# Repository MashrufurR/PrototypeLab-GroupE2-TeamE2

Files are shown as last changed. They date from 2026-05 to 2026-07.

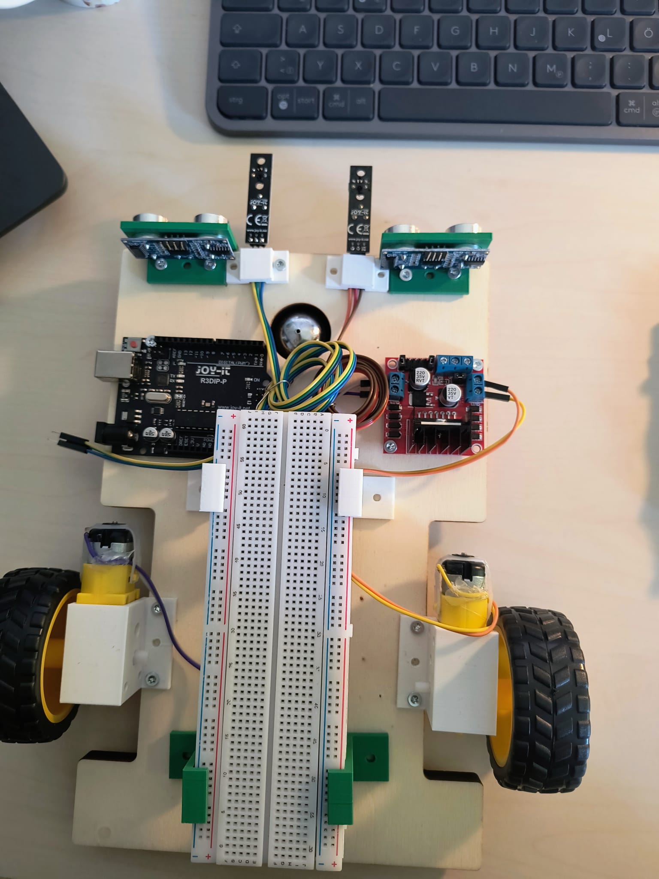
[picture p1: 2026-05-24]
Task1/Final Assemble Update/ Final Assemble.jpg

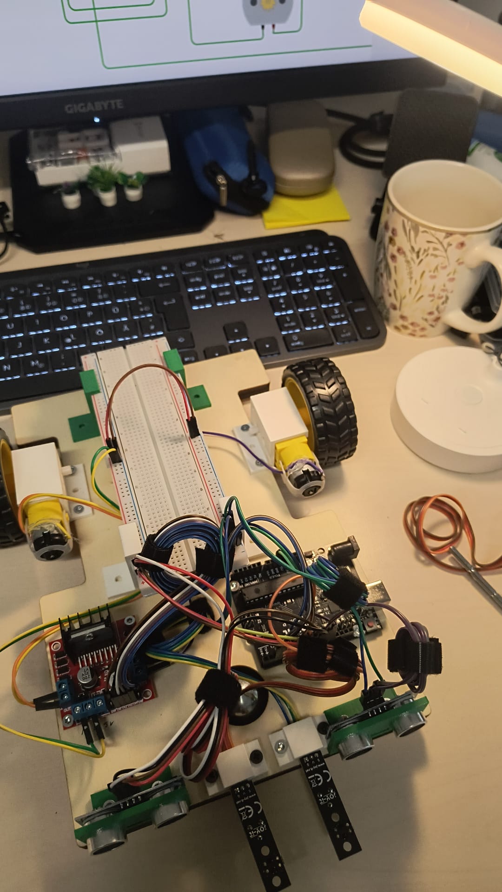
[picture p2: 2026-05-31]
Task1/Final Assemble Update/Update 02.jpg

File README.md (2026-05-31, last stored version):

# Arduino Line-Following Robot — Hardware Connection Guide

A complete wiring and connection reference for the real-life build of the Arduino-based line-following robot with obstacle detection.

---

## Components

| Component | Quantity |
|---|---|
| Arduino Uno | 1 |
| L298N Motor Controller Module | 1 |
| DC Motor | 2 |
| IR Line Sensor | 2 |
| Ultrasonic Sensor (HC-SR04) | 2 |
| Breadboard | 1 |
| 9V Battery | 1 |

> **Note:** The real-life circuit does **not** use switches. The two switches from the Tinkercad simulation are replaced by two IR sensors in the actual build.

---

## Mounting Guidelines

- Arduino and motor controller are **screwed onto the chassis**.
- IR sensors and ultrasonic sensors use **dedicated holders**.
- Glue, tape, and zip ties are **not allowed**.

---

## A. Arduino to Breadboard Power

| From Arduino | To Breadboard |
|---|---|
| 5V | Positive `+` rail |
| GND | Negative `–` rail |

IR sensors and ultrasonic sensors draw power from these breadboard rails.

---

## B. L298N Power Connection

> For the first test, power the Arduino via USB — it is the safest option.

| Connection | Connect To |
|---|---|
| 9V Battery `+` | L298N `12V / VIN` terminal |
| 9V Battery `–` | L298N `GND` terminal |
| L298N `GND` | Arduino GND / Breadboard `–` rail |

**Power flow summary:**
- `9V Battery → L298N → Motors`
- `Arduino USB / 5V → Sensors and Arduino logic`
- `Arduino GND + L298N GND + Sensor GND → Common ground`

### ⚠️ Important Warnings

- Never connect the 9V battery `+` to the Arduino `5V` pin.
- Do not connect the L298N `5V` output pin and Arduino `5V` pin together at this stage.
- A rectangular 9V battery may cause the motors to spin weakly — this is a battery limitation, not a wiring error.

---

## C. L298N Jumper Settings

The L298N module ships with jumper caps on the ENA and ENB pins.

| Jumper | Action |
|---|---|
| ENA jumper | **Remove** |
| ENB jumper | **Remove** |

Motor speed is controlled via Arduino pins D5 (left) and D6 (right):
- **Normal movement** → fast speed
- **Turning** → slow speed
- **Obstacle detected** → motors off

---

## D. L298N to Arduino Control Connections

| L298N Pin | Purpose | Arduino Pin |
|---|---|---|
| ENA | Left motor speed (PWM) | D5 |
| IN1 | Left motor direction 1 | D2 |
| IN2 | Left motor direction 2 | D3 |
| IN3 | Right motor direction 1 | D4 |
| IN4 | Right motor direction 2 | D13 |
| ENB | Right motor speed (PWM) | D6 |
| GND | Common ground | Arduino GND |

---

## E. Motor Connections

| Motor | L298N Terminal |
|---|---|
| Left Motor (terminals 1 & 2) | OUT1 and OUT2 |
| Right Motor (terminals 1 & 2) | OUT3 and OUT4 |

> If a motor spins in the wrong direction during a forward command, **swap the two wires** on that motor's output terminal.

---

## F. IR Sensor Connections

### Left IR Sensor

| IR Sensor Pin | Connect To |
|---|---|
| VCC | Breadboard `+` rail / Arduino 5V |
| GND | Breadboard `–` rail / Arduino GND |
| OUT / DO | Arduino **D7** |

### Right IR Sensor

| IR Sensor Pin | Connect To |
|---|---|
| VCC | Breadboard `+` rail / Arduino 5V |
| GND | Breadboard `–` rail / Arduino GND |
| OUT / DO | Arduino **D8** |

> The Arduino pin assignments (D7 / D8) match the Tinkercad simulation, so **no code changes** are needed for the IR pins.

### Sensor Behavior Note

Some IR sensors output `LOW` when a black line is detected; others output `HIGH`. If the sensor behaves unexpectedly, change this line in the code:

```cpp
const int LINE_DETECTED = LOW;
```

to:

```cpp
const int LINE_DETECTED = HIGH;
```

---

## G. Ultrasonic Sensor Connections

### Left Ultrasonic Sensor (HC-SR04)

| Sensor Pin | Connect To |
|---|---|
| VCC | Breadboard `+` rail / Arduino 5V |
| GND | Breadboard `–` rail / Arduino GND |
| TRIG | Arduino **D9** |
| ECHO | Arduino **D10** |

### Right Ultrasonic Sensor (HC-SR04)

| Sensor Pin | Connect To |
|---|---|
| VCC | Breadboard `+` rail / Arduino 5V |
| GND | Breadboard `–` rail / Arduino GND |
| TRIG | Arduino **D11** |
| ECHO | Arduino **D12** |

---

## H. Complete Arduino Pin Reference

| Arduino Pin | Connected Component |
|---|---|
| 5V | Breadboard positive rail (sensors) |
| GND | Breadboard negative rail + L298N GND |
| D2 | L298N IN1 |
| D3 | L298N IN2 |
| D4 | L298N IN3 |
| D5 | L298N ENA — Left motor speed |
| D6 | L298N ENB — Right motor speed |
| D7 | Left IR Sensor OUT |
| D8 | Right IR Sensor OUT |
| D9 | Left Ultrasonic TRIG |
| D10 | Left Ultrasonic ECHO |
| D11 | Right Ultrasonic TRIG |
| D12 | Right Ultrasonic ECHO |
| D13 | L298N IN4 |

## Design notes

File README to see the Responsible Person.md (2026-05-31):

## Tools We Are Using

- **Tinkercad** — for virtual circuit simulation before physical assembly
- **Arduino IDE** — for writing and uploading code
- **GitHub** — for version control and documentation

---

## Our Team

| Name | Role |
|---|---|
| Aynul | Circuit Diagrams & Schematics |
| Taha | Tinkercad Simulation |
| Jisan | Physical Wiring & Hardware Assembly |
| Mashruf | Arduino Code Development |

### What each of us did so far

**Aynul** drew the full circuit diagrams showing how every component connects — motors, sensors, motor driver, and power lines. This became the reference that the rest of the team worked from.

**Taha** built the virtual simulation in Tinkercad based on Aynuls's diagrams. We used this to verify our wiring logic and pin assignments before touching any real hardware.

**Jisan** took the simulation and assembled it on actual hardware — connecting the breadboard, wiring the L298N motor driver, setting up the motors, and bridging the common ground between all components.

**Mashrufur** started writing the Arduino code — motor control functions, sensor reading logic, and the serial monitor output so we can watch what the robot is sensing in real time.

---

## Current Status

| Task | Status |
|---|---|
| Circuit diagrams | ✅ Done |
| Tinkercad simulation | ✅ Done |
| Physical wiring | ✅ Done |
| Arduino code (base) | 🔄 In progress |
| Real-world testing | ⏳ Upcoming |
| Final calibration | ⏳ Upcoming |

---

## What's Next

- Complete and test the Arduino code on the physical robot
- Run the robot on a test track and adjust sensor thresholds based on real surface readings
- Fine-tune turning speed ratios for smooth line correction
- Document test results and prepare the final project report

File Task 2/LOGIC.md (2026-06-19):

# Line Following Robot - Code Logic

## Overview

The robot follows a black tape line on a white surface using two IR sensors and differential motor control. Every loop cycle it checks for obstacles first, then reads the IR sensors and decides how to move.

---

## Main Loop Flow

```
Every 10ms:
    |
    1. Read both ultrasonic sensors
    |     obstacle closer than 15cm -> brake and stop
    |
    2. Read both IR sensors
    |
    3. Decide movement:
          Both on black  -> go straight
          Left on black  -> turn left
          Right on black -> turn right
          Both off black -> pivot search
```

---

## Line Following Logic

IR sensors output LOW on black tape and HIGH on white floor.

| Left IR | Right IR | Action | Reason |
|---|---|---|---|
| BLACK | BLACK | Go straight | Robot is centred on line |
| BLACK | WHITE | Turn left | Robot drifted right |
| WHITE | BLACK | Turn right | Robot drifted left |
| WHITE | WHITE | Pivot search | Line completely lost |

### Turning - Differential Speed

When turning, the two wheels run at different speeds instead of stopping one wheel completely. This gives a smooth curve rather than a sharp snap.

- Outer wheel runs at TURN_OUTER = 80
- Inner wheel runs at TURN_INNER = 20

The inner wheel still moves forward at low speed. This reduces oscillation and juggling on smooth curves.

### Lost Line Recovery

When both sensors lose the line completely, the robot remembers which direction it last turned using `lastTurnDirection`. It then counter-rotates both wheels in opposite directions to pivot in place toward that direction until one sensor finds black tape again.

- Last turned left -> pivot left: drive(-60, 60)
- Last turned right -> pivot right: drive(60, -60)

This handles sharp U-turns where both sensors briefly lose the line.

---

## Motor Control Logic

The `setMotor` function accepts positive values for forward and negative values for reverse. One motor on the chassis is physically mounted in the opposite direction, so `RIGHT_MOTOR_REVERSED = true` flips its direction in software without changing any wiring.

### Active Brake

`brakeNow()` sets both IN pins HIGH with full PWM instead of just cutting power to zero. This locks the motor shaft immediately instead of letting the robot coast forward.

---

## Obstacle Detection

Both ultrasonic sensors are read every loop cycle before any motor decision is made. If either sensor reads a distance below 15cm the robot brakes immediately and skips the rest of the loop. This gives obstacle detection the highest priority over line following.

---

## Speed Constants

| Constant | Value | Purpose |
|---|---|---|
| FORWARD_SPEED | 80 | Both wheels straight |
| TURN_OUTER | 80 | Outside wheel during turn |
| TURN_INNER | 20 | Inside wheel during turn |
| SEARCH_SPEED | 60 | Pivot speed when line lost |
| STOP_DISTANCE | 15.0 cm | Obstacle brake threshold |

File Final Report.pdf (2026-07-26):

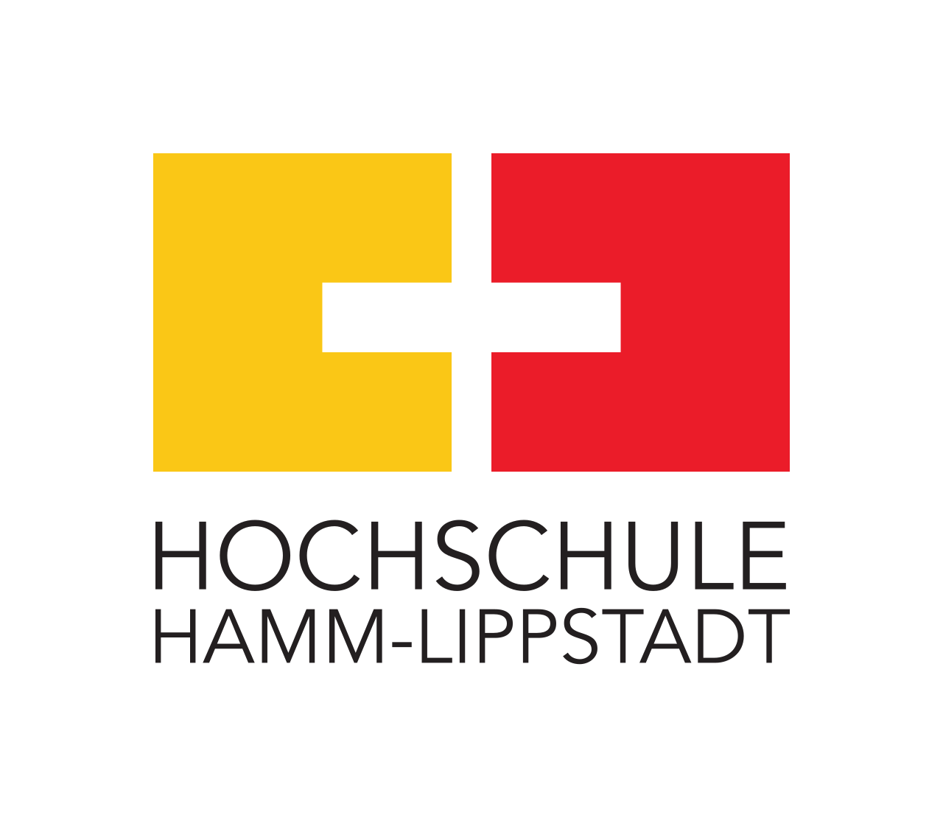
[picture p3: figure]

# ARDUINO-BASED LINE FOLLOWING ROBOT PROTOTYPE & SYSTEMS ENGINEERING

# PROJECT REPORT

## Course: Prototype & System Engineering Institution: Hochschule Hamm-Lippstadt (HSHL) Supervisor: Dr. Faezeh Pasandideh & Fatema Idress

Name | ID
Syed Jisan Ahmed | 1233545
K M Mashrufur Rahman | 1233549
Md Aynul Haque | 1233987
Mohammad Taha Hossain Chowdhury | 1234063

Team E2 · Electronic Engineering · HSHL · Page 1

### 1. Introduction & Objectives

Autonomous mechatronic systems are now central to modern industrial logistics — from warehouse AGVs to assembly-line inspection. This report documents the complete development of an Arduino-based line-following robot built for the Prototype & System Engineering course at HSHL. The project followed the full engineering lifecycle: requirements definition, CAD design, virtual simulation, physical assembly, embedded programming, and hardware debugging.

The system was built to meet four operational objectives:
- Continuous Line Sensing: detect a 22 mm black tape on white surface using dual TCRT5000 IR sensors.
- Obstacle Avoidance: detect objects within 25 cm using HC-SR04 ultrasonic sensors, stop safely, execute a geometric detour, and re-acquire the line.
- State-Dependent Maneuvering (Bonus): on detection of a second obstacle, execute a 180° in-place U-turn and reverse course.
- Structural Integrity: all components mounted using custom CAD-designed brackets. No glue, tape, or zip ties.

### 2. System Design & Engineering Approach

Rather than building by trial and error, the team used a structured Virtual-to-Physical (V2P) validation approach:

- Virtual Prototype: the complete circuit was modelled in Tinkercad. Push-button switches stood in for IR and ultrasonic sensors. This caught an IN3/IN4 wiring reversal before any hardware was connected.
- Breadboard Integration: a shared common ground was established across all modules. Without this, floating voltages caused random IR sensor outputs during initial testing.
- Physical Assembly: custom SolidWorks-designed holders were fabricated for motors, IR sensors, ultrasonic sensors, and battery/breadboard. This eliminated improvised mounting and ensured repeatable sensor geometry.

One significant design revision occurred during assembly: the original CAD placed IR sensors on top of the chassis, but wheel hardware blocked that position. A revised bracket was designed and fitted, mounting the sensors underneath at 5–6 mm ground clearance and 18–20 mm lateral spacing — within the optimal range for the TCRT5000 reading a 22 mm tape.

### 3. Hardware & Software Implementation

### 3.1 Hardware Architecture

Component | Model | Qty | Function
Microcontroller | Arduino Uno R3 | 1 | Central processing unit
Motor Driver | L298N | 1 | PWM speed & direction control
DC Motors | TT Gear Motor | 2 | Differential drive
IR Sensors | TCRT5000 | 2 | Line detection

The ENA and ENB enable jumpers on the L298N were removed to allow the Arduino to send PWM signals through pins D5 and D6, enabling variable speed control via analogWrite(). With jumpers installed, motors run at fixed maximum power with no speed regulation.

### 3.2 Pin Configuration

### 3.3 Software Logic

The software runs as a continuous polling loop with strict state-tracking variables managing all concurrent behaviour.

Line Following — Decision Table

When both sensors read WHITE simultaneously — common on tight curves — the lastTurnDirection variable (-1 left, 1 right) directs a pivot back toward where the line was last detected at
SEARCH_SPEED = 45 PWM.

Distance Measurement: HC-SR04 distance is calculated as:

Ultrasonic Sensors | HC-SR04 | 2 | Obstacle distance measurement
Battery | 9 V Alkaline | 1 | System power supply
Chassis | 2WD Acrylic Kit | 1 | Mechanical platform
Arduino Pin | Connected To | Direction | Function
D2, D3 | IN1, IN2 | OUT | Left motor direction
D4, D13 | IN3, IN4 | OUT | Right motor direction
D5 (PWM) | ENA | OUT | Left motor speed
D6 (PWM) | ENB | OUT | Right motor speed
D7, D8 | Left/Right IR | IN | Line sensor readings
D9, D10 | Left TRIG/ECHO | OUT/IN | Left ultrasonic
D11, D12 | Right TRIG/ECHO | OUT/IN | Right ultrasonic
GND | Common rail | — | Shared ground for all modules
Left IR | Right IR | Action | Meaning
BLACK | BLACK | drive(75, 75) | Centred — straight ahead
BLACK | WHITE | drive(15, 80) | Drifted right — correct left
WHITE | BLACK | drive(80, 15) | Drifted left — correct right
WHITE | WHITE | Pivot via lastTurnDirection | Line lost — recover from memory

distance (cm) = duration (µs) × 0.0343 ÷ 2
The pulseIn timeout was set to 30000 µs, covering the full usable range of the sensor (~514 cm). The original 12000 µs timeout caused readings to return 0 on some cycles, which were misinterpreted as no obstacle present — leading to missed detections.

Motor Reversal Flag: The right motor was physically mounted in the reverse orientation. Rather than rewiring it, a
RIGHT_MOTOR_REVERSED = true flag inside setMotor() inverts the speed value before setting direction pins. This corrects the physical reversal transparently at the driver level, so all higher-level steering commands use standard logical values.

### 4. Obstacle Avoidance & U-Turn Logic

### 4.1 Geometric Bypass Sequence

When either ultrasonic sensor reads below 25 cm, the avoidObstacle() function is triggered. The maneuver is a timed open-loop sequence:

During Steps 7 and 8, the robot crawls at 35–45 PWM with IR sensors sampled every 2 ms. This sampling frequency ensures the 22 mm tape cannot pass beneath the sensors between cycles at the reduced speed. If the line is detected, a lock-on phase applies micro-corrections (nudge left or right) until both sensors confirm centre position.

4.2 180° U-Turn (Bonus Task)
An obstacleCount integer tracks cumulative detections. On the first obstacle, normal avoidance runs. On the second, uTurn180() is called:

void uTurn180() {
brakeNow(); delay(300);
drive(80, 0); | // single wheel pivot
delay(1500); | // tune for exact 180° on surface
brakeNow(); delay(200);
Step | Action | Duration | Purpose
1 | Hard brake | 500 ms | Full stop — no coasting into box
2 | Pivot right | 340 ms @ speed 95 | Swing nose clear of obstacle
3 | Forward diagonal | 650 ms @ speed 75 | Clear obstacle side
4 | Pivot left | 340 ms @ speed 95 | Re-align parallel to heading
5 | Forward straight | 1000 ms @ speed 75 | Clear obstacle length
6 | Pivot left inward | 370 ms @ speed 95 | Angle back toward line
7 | Slow creep + IR scan | Up to 600 ms | Detect line at low speed
8 | Turn 4 + extended crawl | Up to 5000 ms | Secondary search if missed

obstacleCount = 0; // reset for next lap }

After the U-turn, normal line following resumes in the opposite direction along the same circular track. The 1500 ms duration was determined through physical calibration on the test surface.

### 5. Challenges & Solutions

Momentum Coasting: Setting motor speed to zero allowed 8–10 cm of post-stop coasting at operating speed. The robot made contact with the obstacle in early tests.

Solution: A brakeNow() function was implemented that sets all IN direction pins HIGH while applying maximum PWM simultaneously — creating an electrical short-circuit braking effect that locks the motors instantly.

Line Missed After Avoidance: After the bypass maneuver, the robot repeatedly crossed the 22 mm tape without the IR sensors registering it. At speeds above ~20 PWM, sampling was too infrequent relative to travel speed.

Solution: Creep speed reduced to 35–45 PWM. Sensors sampled every 2 ms inside a tight while loop. A secondary four-turn search sequence was added as a fallback if the primary search times out.

360° Spinning Instead of Pivoting: Early pivot commands using negative speed values caused continuous spinning. The RIGHT_MOTOR_REVERSED flag was double-inverting the sign — both wheels ended up rotating the same direction.

Solution: Pivot commands changed to drive(SHARP_TURN_SPEED, −SHARP_TURN_SPEED). After the internal flag applies one inversion to the right motor, the result correctly produces opposing wheel directions.

IR Sensor Placement: The original CAD mounted sensors on top of the chassis. Wheel hardware blocked this position during assembly. Sensors needed to be at 5–6 mm ground clearance to detect the tape reliably.

Solution: A revised bracket was designed and fitted during the build, repositioning sensors underneath the chassis. Height and lateral spacing (18–20 mm) were measured and verified before permanent installation.

Dropped Ultrasonic Readings: The original pulseIn timeout of 12000 µs caused the function to return 0 on some cycles — treated as 999 cm by the code. Genuine obstacle detections were silently dropped.

Solution: Timeout increased to 30000 µs, covering the full HC-SR04 detection range. All readings within sensor specification are now captured reliably.

### 6. Conclusions & Future Improvements

Team E2 designed, simulated, assembled, and programmed a fully functional autonomous robot that reliably follows a line, avoids a physical obstacle, and executes a 180° directional reversal on the second obstacle encounter. The project was completed through a systematic engineering approach — virtual validation before hardware contact, structured debugging, and iterative physical tuning.

The most important lessons came from hardware — not simulation. The ENA/ENB physical reversal, the double sign-flip in motor logic, the dropped ultrasonic readings, and the IR sensor placement revision were all problems that only appeared when the robot was running on the actual track. Each one was diagnosed methodically and resolved without redesigning the broader system.

Future Improvements
- PID Line Control: replace discrete bang-bang turning with a Proportional-Integral-Derivative controller to eliminate micro-oscillations and produce smoother tracking on straight sections.
- Rechargeable Power: the 9 V alkaline battery suffers voltage sag as it drains, subtly altering motor speed and affecting the accuracy of timed maneuver steps. A Li-ion pack with a stepdown voltage regulator would deliver consistent power across the full operational period.
- Bluetooth Override: an HC-05 module would allow real-time parameter adjustment and manual override without re-uploading code.
- Maze-Solving Extension: the existing obstacle avoidance logic could be extended into a lefthand rule or flood-fill maze-solving algorithm for more complex navigation scenarios.

### References

[1] Arduino LLC. Arduino Uno R3 Official Documentation. https://docs.arduino.cc
[2] STMicroelectronics. L298N Dual Full-Bridge Driver Datasheet.
[3] Vishay Semiconductors. TCRT5000 Reflective Optical Sensor Datasheet.
[4] HC-SR04 Ultrasonic Ranging Module — Technical Specification. Cytron Technologies.
[5] Autodesk Inc. Tinkercad Circuit Simulator. https://www.tinkercad.com
[6] Dassault Systèmes. SolidWorks CAD Software. https://www.solidworks.com
[7] Course Materials — Prototype & System Engineering, HSHL, 2025/2026.

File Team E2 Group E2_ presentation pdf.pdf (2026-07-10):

# Arduino-Based Line

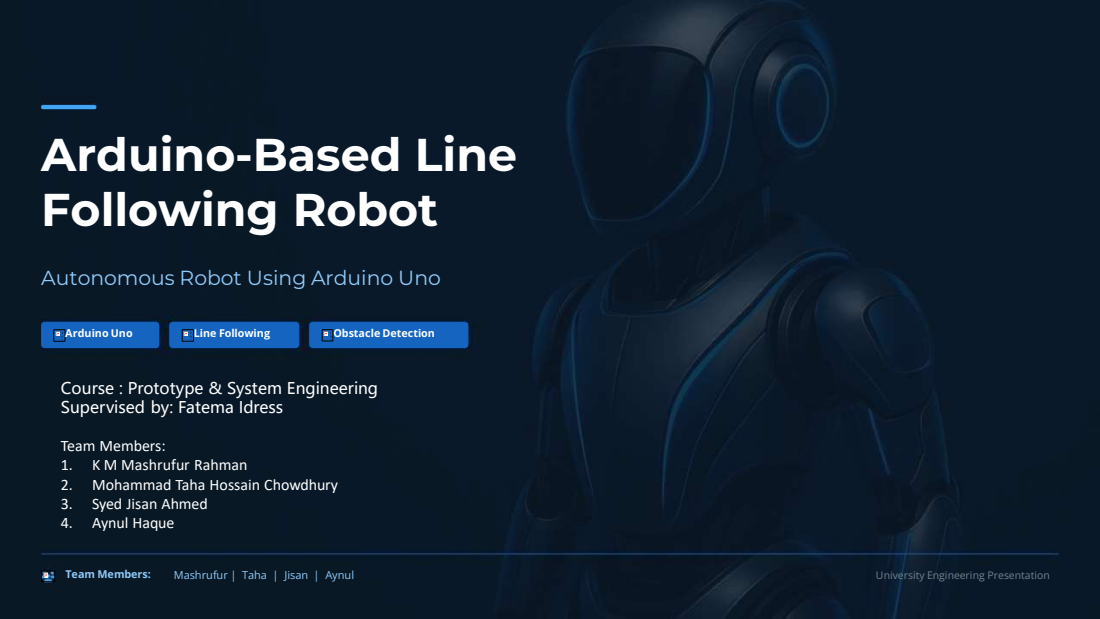
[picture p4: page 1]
Following Robot; Arduino Uno; Line Following; Obstacle Detection; Team Members:; Mashrufur | Taha | Jisan | Aynul; University Engineering Presentation

Autonomous Robot Using Arduino Uno

Course : Prototype & System Engineering
Supervised by: Fatema Idress

Team Members:
1. K M Mashrufur Rahman
2. Mohammad Taha Hossain Chowdhury
3. Syed Jisan Ahmed
4. Aynul Haque

# Project Objectives

Build a fully autonomous robot that follows lines, detects obstacles, and responds safely — from design through

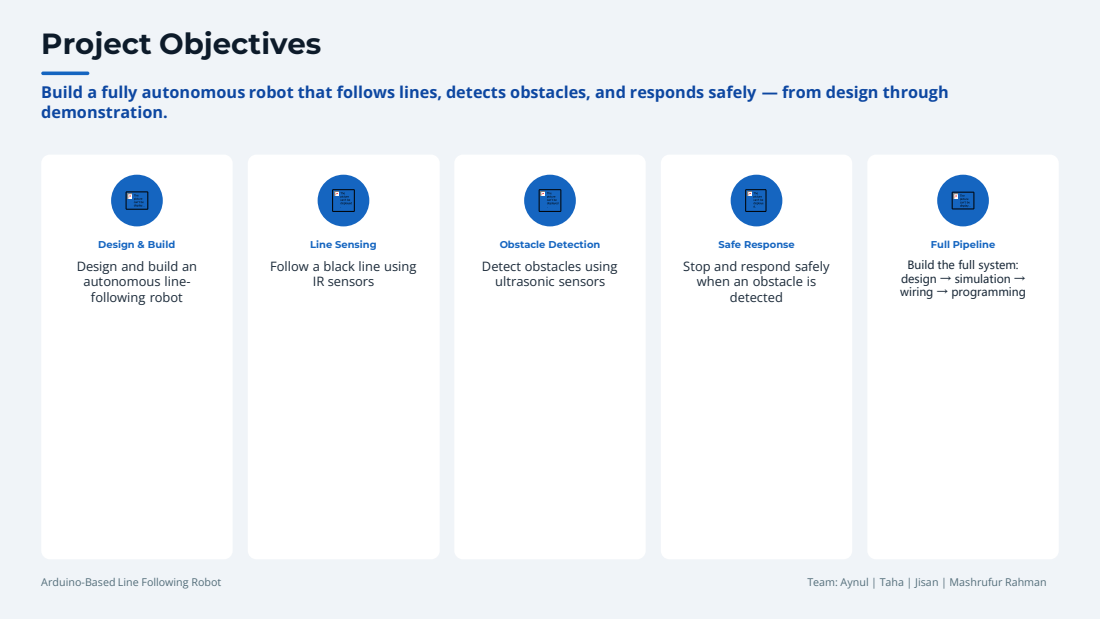
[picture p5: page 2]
demonstration.; Arduino-Based Line Following Robot; Team: Aynul | Taha | Jisan | Mashrufur Rahman

Design & Build
Design and build an
autonomous line-
following robot

Line Sensing
Follow a black line using
IR sensors

Obstacle Detection
Detect obstacles using
ultrasonic sensors

Safe Response
Stop and respond safely
when an obstacle is
detected

Full Pipeline
Build the full system:
design → simulation →
wiring → programming

# Robot Design and Holders

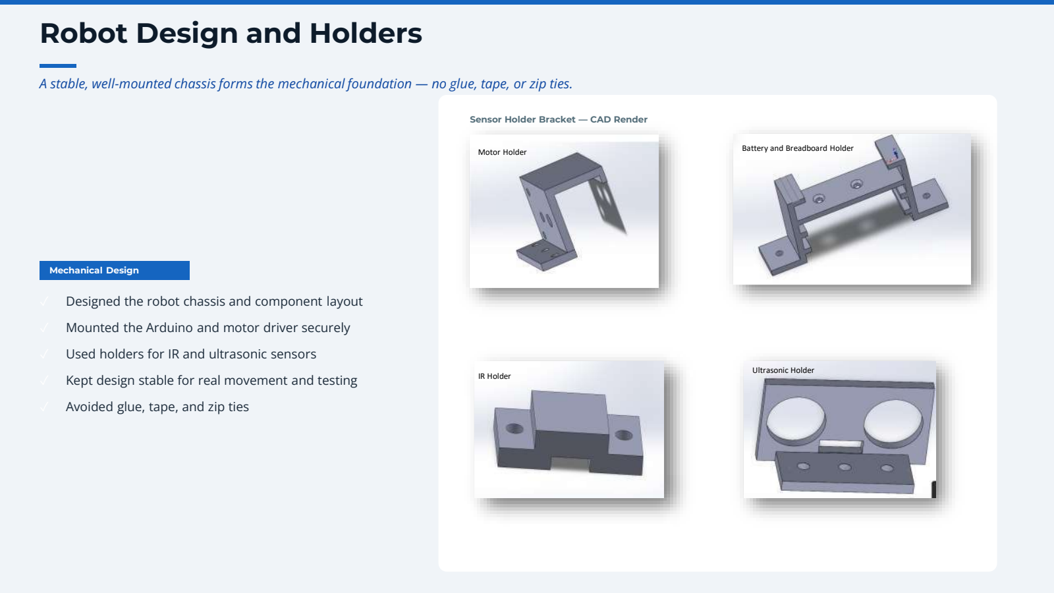
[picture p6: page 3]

A stable, well-mounted chassis forms the mechanical foundation — no glue, tape, or zip ties.

Mechanical Design

Sensor Holder Bracket — CAD Render

✓ | Designed the robot chassis and component layout
✓ | Mounted the Arduino and motor driver securely
✓ | Used holders for IR and ultrasonic sensors
✓ | Kept design stable for real movement and testing
✓ | Avoided glue, tape, and zip ties

Motor Holder

IR Holder

Battery and Breadboard Holder

Ultrasonic Holder

# Circuit Diagram & Connection Plan

A complete circuit diagram was planned before any hardware assembly — ensuring correct pin assignments and a clean common ground.

Connection Flow

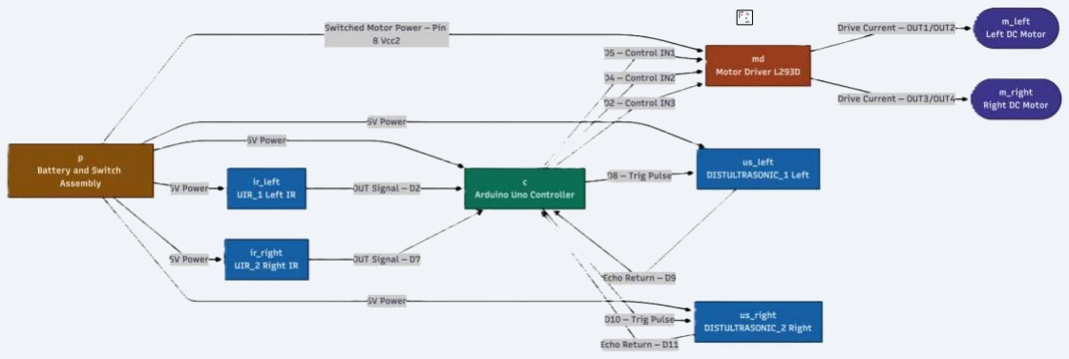
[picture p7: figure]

Arduino-Based Line Following Robot | 04
- Created the full circuit diagram before hardware assembly
- Assigned Arduino pins for motors, sensors, and power
- Made the circuit easy to follow for simulation and hardware implementation

# Tinkercad Simulation

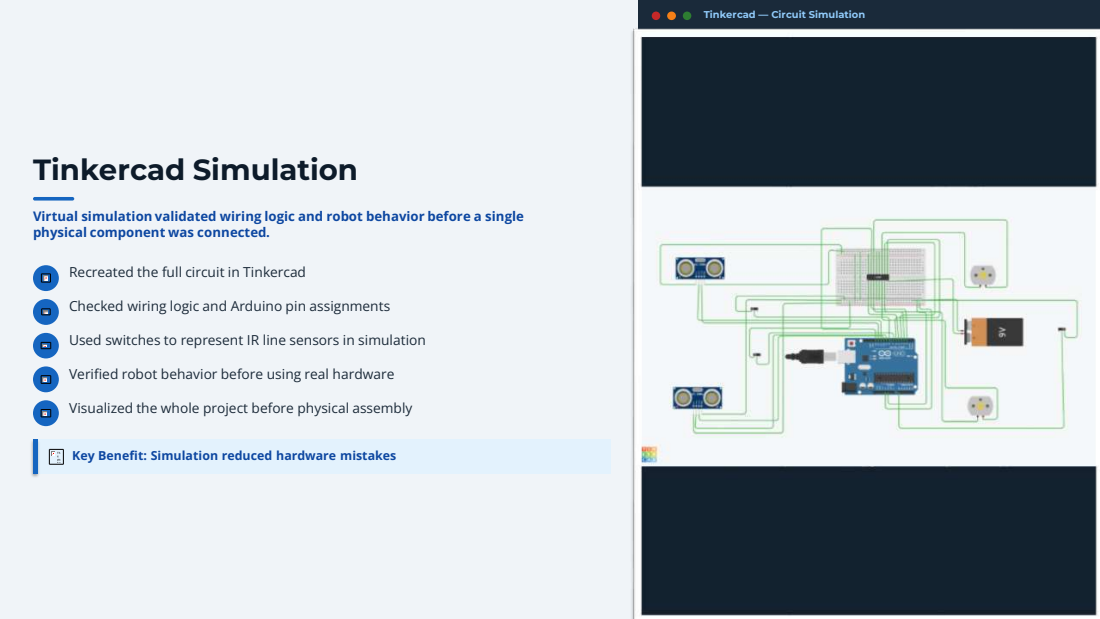
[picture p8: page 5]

Tinkercad — Circuit Simulation

Virtual simulation validated wiring logic and robot behavior before a single
physical component was connected.

Recreated the full circuit in Tinkercad
Checked wiring logic and Arduino pin assignments
Used switches to represent IR line sensors in simulation
Verified robot behavior before using real hardware
Visualized the whole project before physical assembly

Key Benefit: Simulation reduced hardware mistakes

# Physical Wiring & Assembly

### The circuit diagram was translated into a complete physical build with

all modules properly wired and grounded.

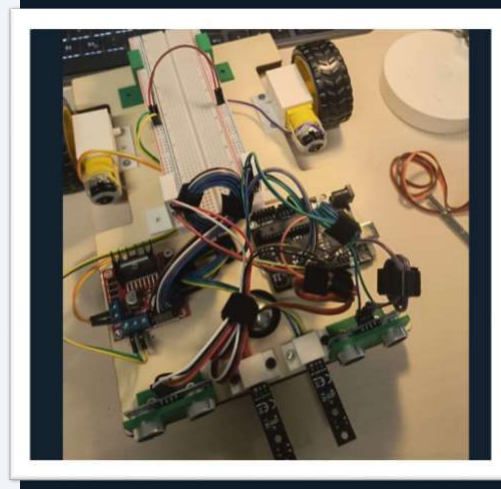
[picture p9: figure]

Hardware Implementation

Arduino-Based Line Following Robot — Physical Assembly

- Converted the diagram into a real physical build
- Connected breadboard, motor driver, motors, sensors, and battery
- Wired IR sensors and ultrasonic sensors to assigned pins
- Removed ENA and ENB jumpers for PWM speed control
- Connected a common ground between all modules

# Demonstration

The robot successfully performs three behaviors: line following, obstacle avoidance, and 180-degree U-turn.

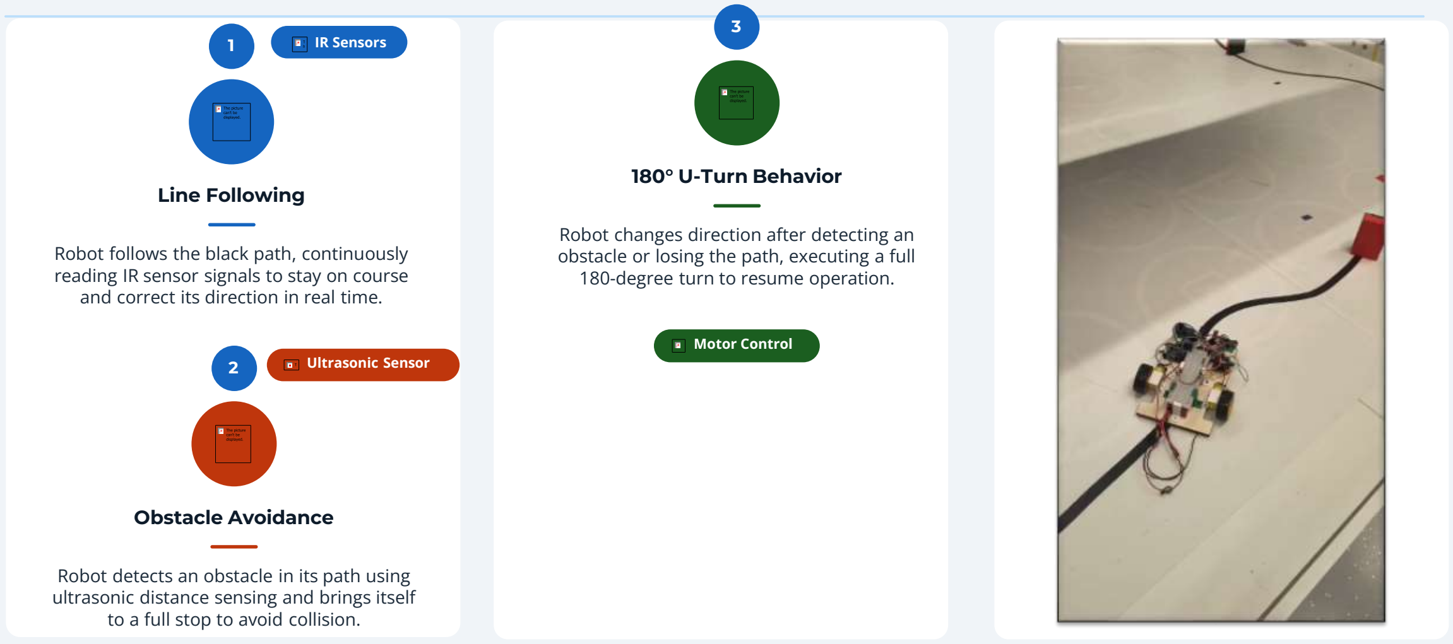
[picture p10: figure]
Line Following; and correct its direction in real time.; IR Sensors; Obstacle Avoidance; to a full stop to avoid collision.; Ultrasonic Sensor; 180° U-Turn Behavior; 180-degree turn to resume operation.; Motor Control

Robot follows the black path, continuously reading IR sensor signals to stay on course

Robot detects an obstacle in its path using ultrasonic distance sensing and brings itself

Robot changes direction after detecting an obstacle or losing the path, executing a full

Arduino-Based Line Following Robot | 7 / 9

# Challenges & Future Improvements

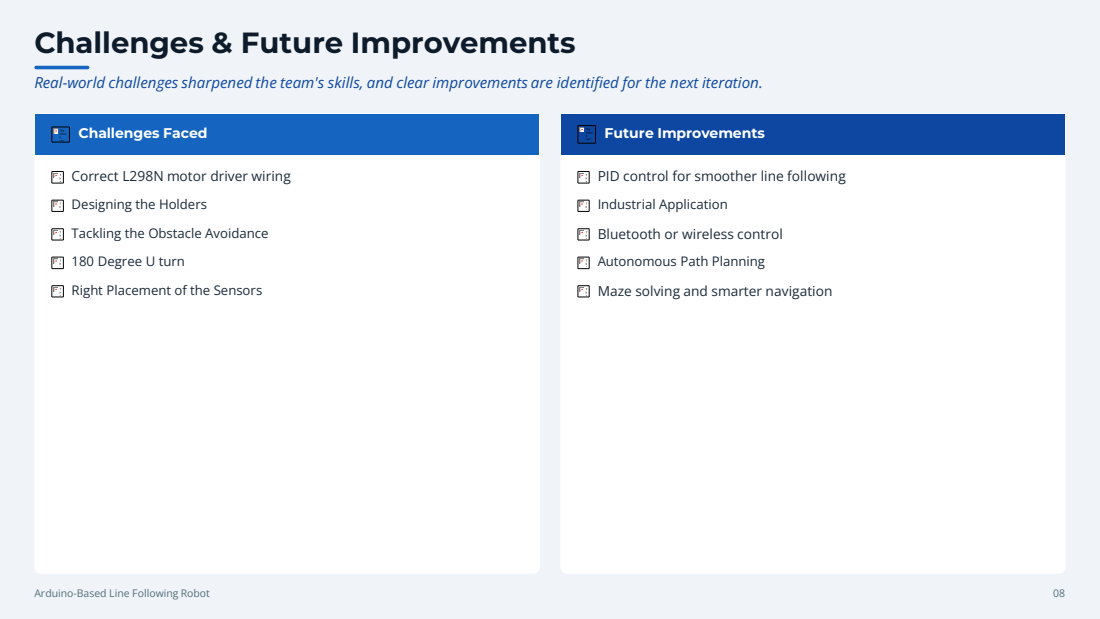
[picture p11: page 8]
Challenges Faced; Future Improvements; Arduino-Based Line Following Robot

Real-world challenges sharpened the team's skills, and clear improvements are identified for the next iteration.

Correct L298N motor driver wiring
Designing the Holders
Tackling the Obstacle Avoidance
180 Degree U turn
Right Placement of the Sensors

PID control for smoother line following
Industrial Application
Bluetooth or wireless control
Autonomous Path Planning
Maze solving and smarter navigation

Final Slide

# Conclusion

Through teamwork, simulation, and iterative testing, the team successfully delivered a fully functional autonomous robot.

Thank You
Questions?

Key Achievements

Design, Simulation, Wiring & Programming
Successfully completed the full development lifecycle from concept to working hardware

Unified Line Following & Obstacle Detection
Combined IR sensor-based line tracking and ultrasonic obstacle avoidance in one system

Teamwork & Systematic Testing
Delivered the project through collaborative effort and structured iterative testing
Design | Simulation | Wiring | Programming | Demo
Team: Aynul | Taha | Jisan | Mashrufur Rahman | 9 / 9

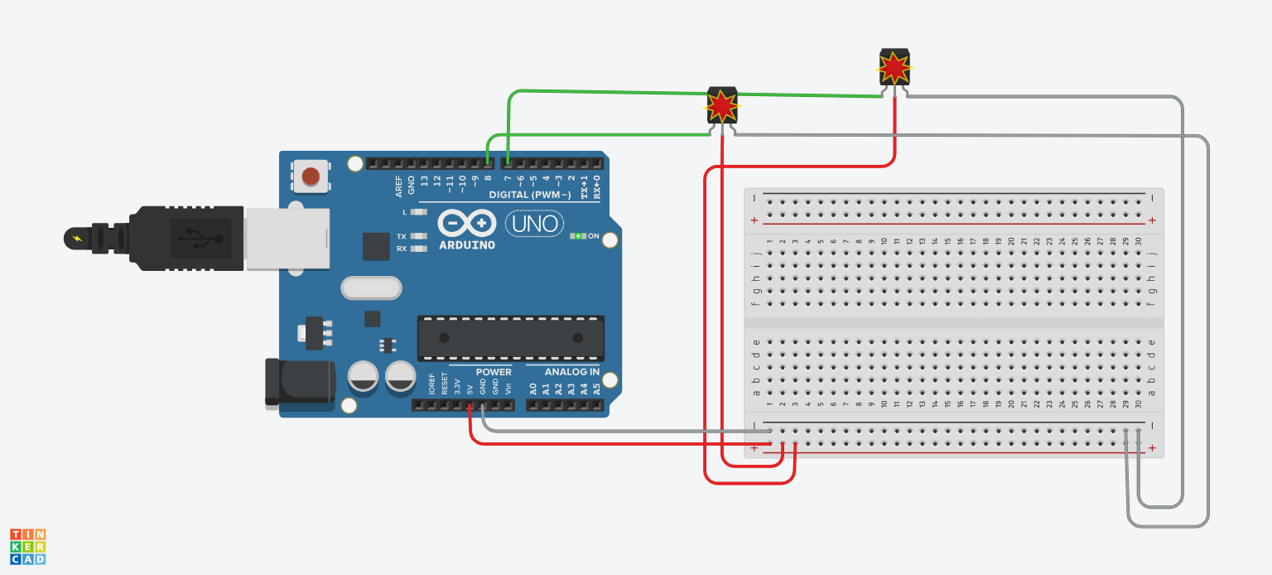
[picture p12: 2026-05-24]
Task1/Tinkercad/Individual Pin Diagrams/IR sensor/IR Sensors.png

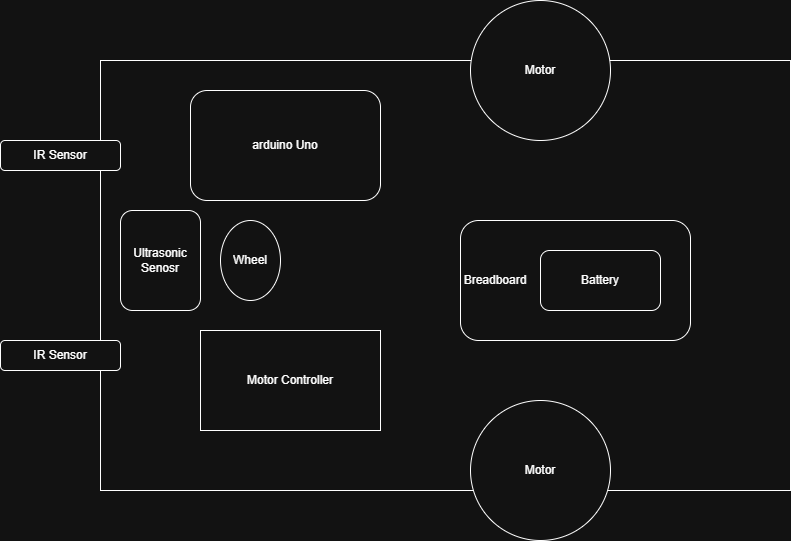
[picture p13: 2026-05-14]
Task1/Diagram/Diagram.drawio.png

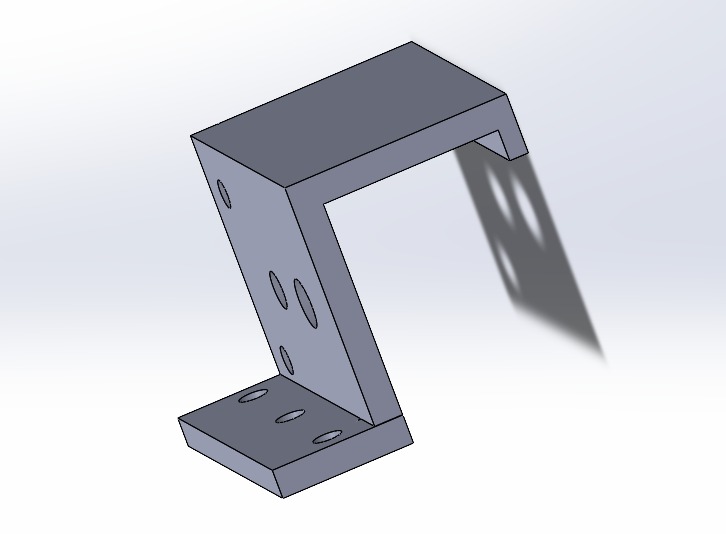
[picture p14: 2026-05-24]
Task1/Holders/Motor_Holder.jpeg

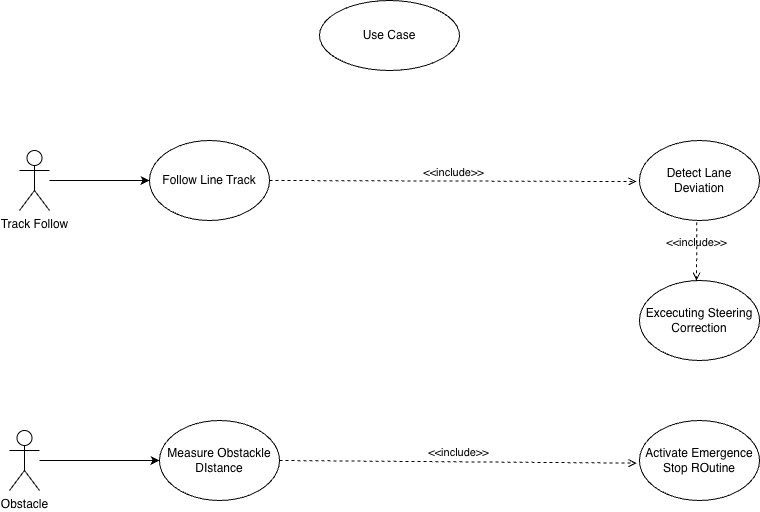
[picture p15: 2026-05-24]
Task1/Diagram/use case diagram.png

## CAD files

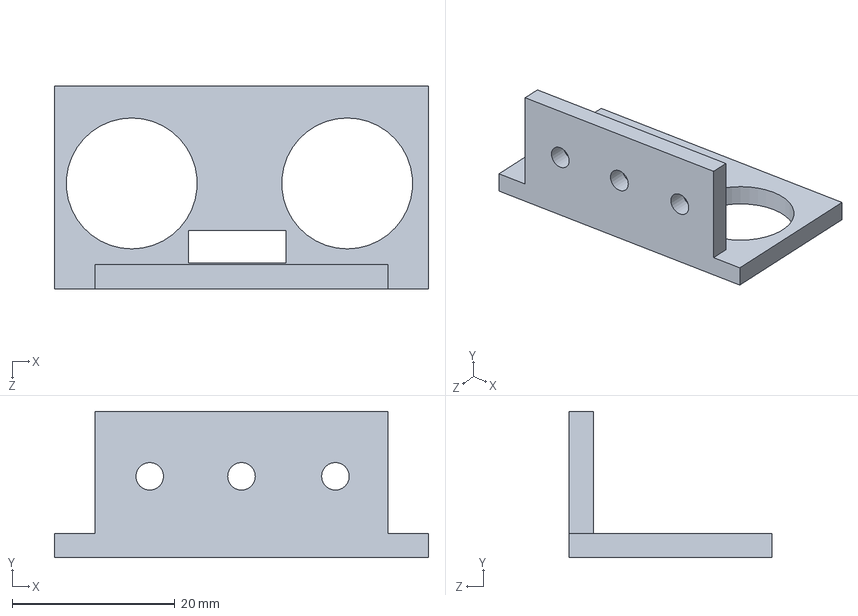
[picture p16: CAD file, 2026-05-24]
Task1/Holders/Final Untrasonic.SLDPRT
46.0 x 18.0 x 25.0 mm

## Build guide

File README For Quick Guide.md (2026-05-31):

# Line Following Robot

This is the hardware connection guide for our Arduino-based line following robot. We built this for real-life use, so if you're coming from the Tinkercad simulation, note that we replaced the two switches with actual IR sensors here.

---

## What We Used

| Component | How Many |
|---|---|
| Arduino Uno | 1 |
| L298N Motor Driver | 1 |
| DC Motor | 2 |
| IR Line Sensor | 2 |
| HC-SR04 Ultrasonic Sensor | 2 |
| Breadboard | 1 |
| 9V Battery | 1 |

---

## How We Mounted Everything

We screwed the Arduino and motor driver directly onto the chassis. For the IR and ultrasonic sensors, we used proper sensor holders. We did not use any glue, tape, or zip ties — that's a hard rule in our design guidelines.

---

## A. Powering the Breadboard from Arduino

This is the first thing we connect. The sensors all draw power from the breadboard rails.

| Arduino | Breadboard |
|---|---|
| 5V | `+` positive rail |
| GND | `–` negative rail |

---

## B. Connecting the 9V Battery to L298N

For our first test we always power the Arduino through USB — it's safer and easier to debug.

| What | Where it goes |
|---|---|
| 9V Battery `+` | L298N `VIN / 12V` terminal |
| 9V Battery `–` | L298N `GND` terminal |
| L298N `GND` | Arduino GND (and breadboard `–` rail) |

## C. The ENA / ENB Jumpers on L298N

By default the L298N comes with jumper caps sitting on the ENA and ENB pins. We need to remove both of them.

| Jumper | What to do |
|---|---|
| ENA | Pull it off |
| ENB | Pull it off |

We do this because we want to control motor speed ourselves from the Arduino. We use D5 for the left motor and D6 for the right. The way our code works — normal driving is full speed, turning slows one side down, and if an obstacle shows up the motors stop completely.

---

## D. L298N to Arduino

| L298N Pin | What it does | Arduino Pin |
|---|---|---|
| ENA | Left motor speed | D5 |
| IN1 | Left motor direction | D2 |
| IN2 | Left motor direction | D3 |
| IN3 | Right motor direction | D4 |
| IN4 | Right motor direction | D13 |
| ENB | Right motor speed | D6 |
| GND | Common ground | GND |

---

## E. Motors to L298N

| Motor | L298N Output |
|---|---|
| Left motor (2 wires) | OUT1 and OUT2 |
| Right motor (2 wires) | OUT3 and OUT4 |

One thing that often happens during first testing — if we send a forward command and one motor spins backwards, we just swap that motor's two wires on the output terminal. No code change needed.

---

## F. IR Sensors

In Tinkercad we had Switch 1 on D7 and Switch 2 on D8. In the real build, our IR sensors go to the exact same pins, so we didn't have to change anything in the code.

**Left IR Sensor**

| Sensor Pin | Connect to |
|---|---|
| VCC | Breadboard `+` rail |
| GND | Breadboard `–` rail |
| OUT | Arduino D7 |

**Right IR Sensor**

| Sensor Pin | Connect to |
|---|---|
| VCC | Breadboard `+` rail |
| GND | Breadboard `–` rail |
| OUT | Arduino D8 |

One thing we noticed — some IR sensors give `LOW` when they detect a black line, and some give `HIGH`. If our robot behaves weirdly on the line, we try flipping this one line in the code:

```cpp
// default
const int LINE_DETECTED = LOW;

// change to this if the sensor is inverted
const int LINE_DETECTED = HIGH;
```

---

## G. Ultrasonic Sensors

**Left HC-SR04**

| Sensor Pin | Connect to |
|---|---|
| VCC | Breadboard `+` rail |
| GND | Breadboard `–` rail |
| TRIG | Arduino D9 |
| ECHO | Arduino D10 |

**Right HC-SR04**

| Sensor Pin | Connect to |
|---|---|
| VCC | Breadboard `+` rail |
| GND | Breadboard `–` rail |
| TRIG | Arduino D11 |
| ECHO | Arduino D12 |

---

## H. Full Pin Summary

This is the complete picture of what goes where on the Arduino.

| Arduino Pin | What's connected |
|---|---|
| 5V | Breadboard `+` rail |
| GND | Breadboard `–` rail and L298N GND |
| D2 | L298N IN1 |
| D3 | L298N IN2 |
| D4 | L298N IN3 |
| D5 | L298N ENA (left motor speed) |
| D6 | L298N ENB (right motor speed) |
| D7 | Left IR sensor OUT |
| D8 | Right IR sensor OUT |
| D9 | Left ultrasonic TRIG |
| D10 | Left ultrasonic ECHO |
| D11 | Right ultrasonic TRIG |
| D12 | Right ultrasonic ECHO |
| D13 | L298N IN4 |

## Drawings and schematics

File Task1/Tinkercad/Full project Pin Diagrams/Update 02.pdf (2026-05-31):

A

1 | 2 | 3 | 4 | 5 | 6

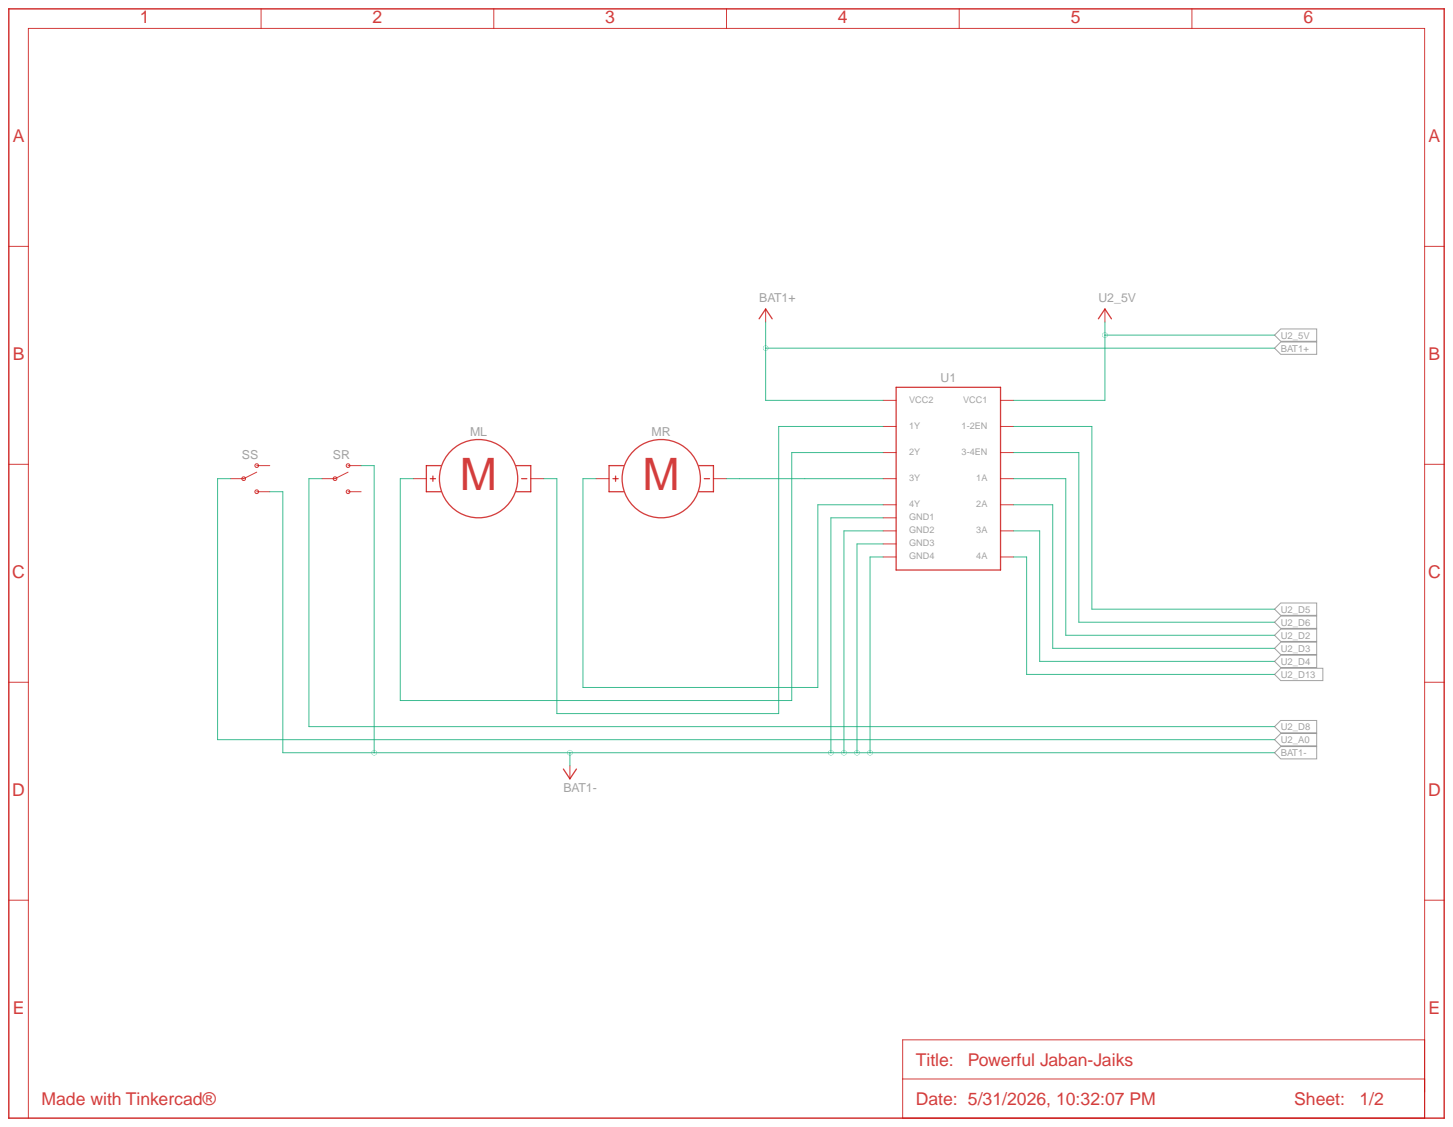
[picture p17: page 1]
Date: 5/31/2026, 10:32:07 PM; Sheet: 1/2; GND1 GND2; VCC2; VCC1; GND3 GND4; BAT1+; BAT1-

Title: Powerful Jaban-Jaiks

Made with Tinkercad®

A

1 | 2 | 3 | 4 | 5 | 6

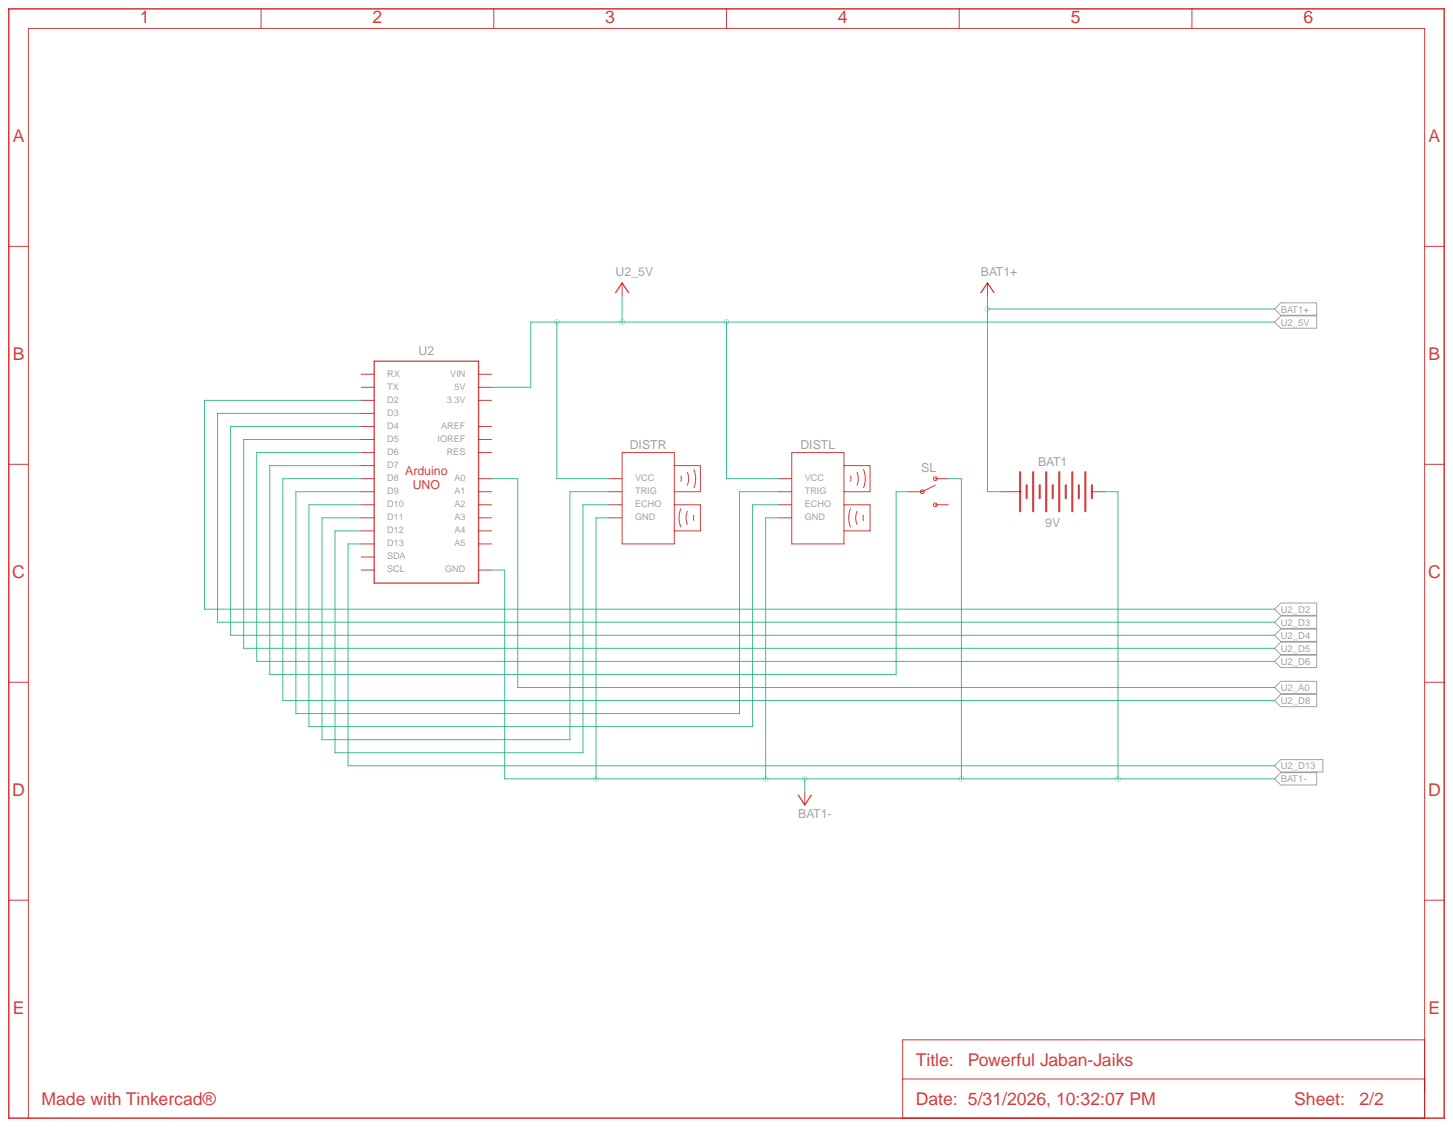
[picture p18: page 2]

Title: Powerful Jaban-Jaiks

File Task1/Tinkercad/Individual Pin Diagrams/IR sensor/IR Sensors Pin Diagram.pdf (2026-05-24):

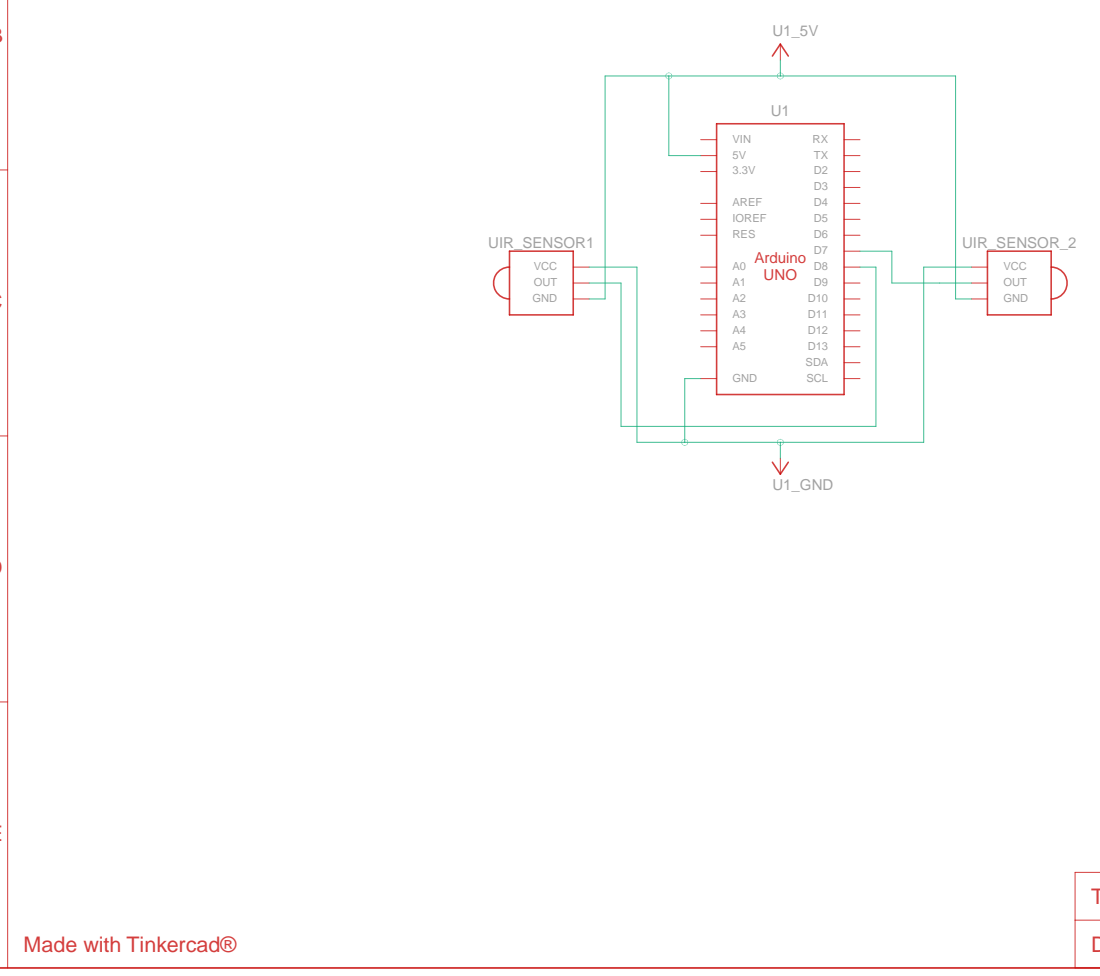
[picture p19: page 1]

Title: IR Sensors AYNUL

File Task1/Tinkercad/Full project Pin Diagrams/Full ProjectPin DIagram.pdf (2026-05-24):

A

1 | 2 | 3 | 4 | 5 | 6

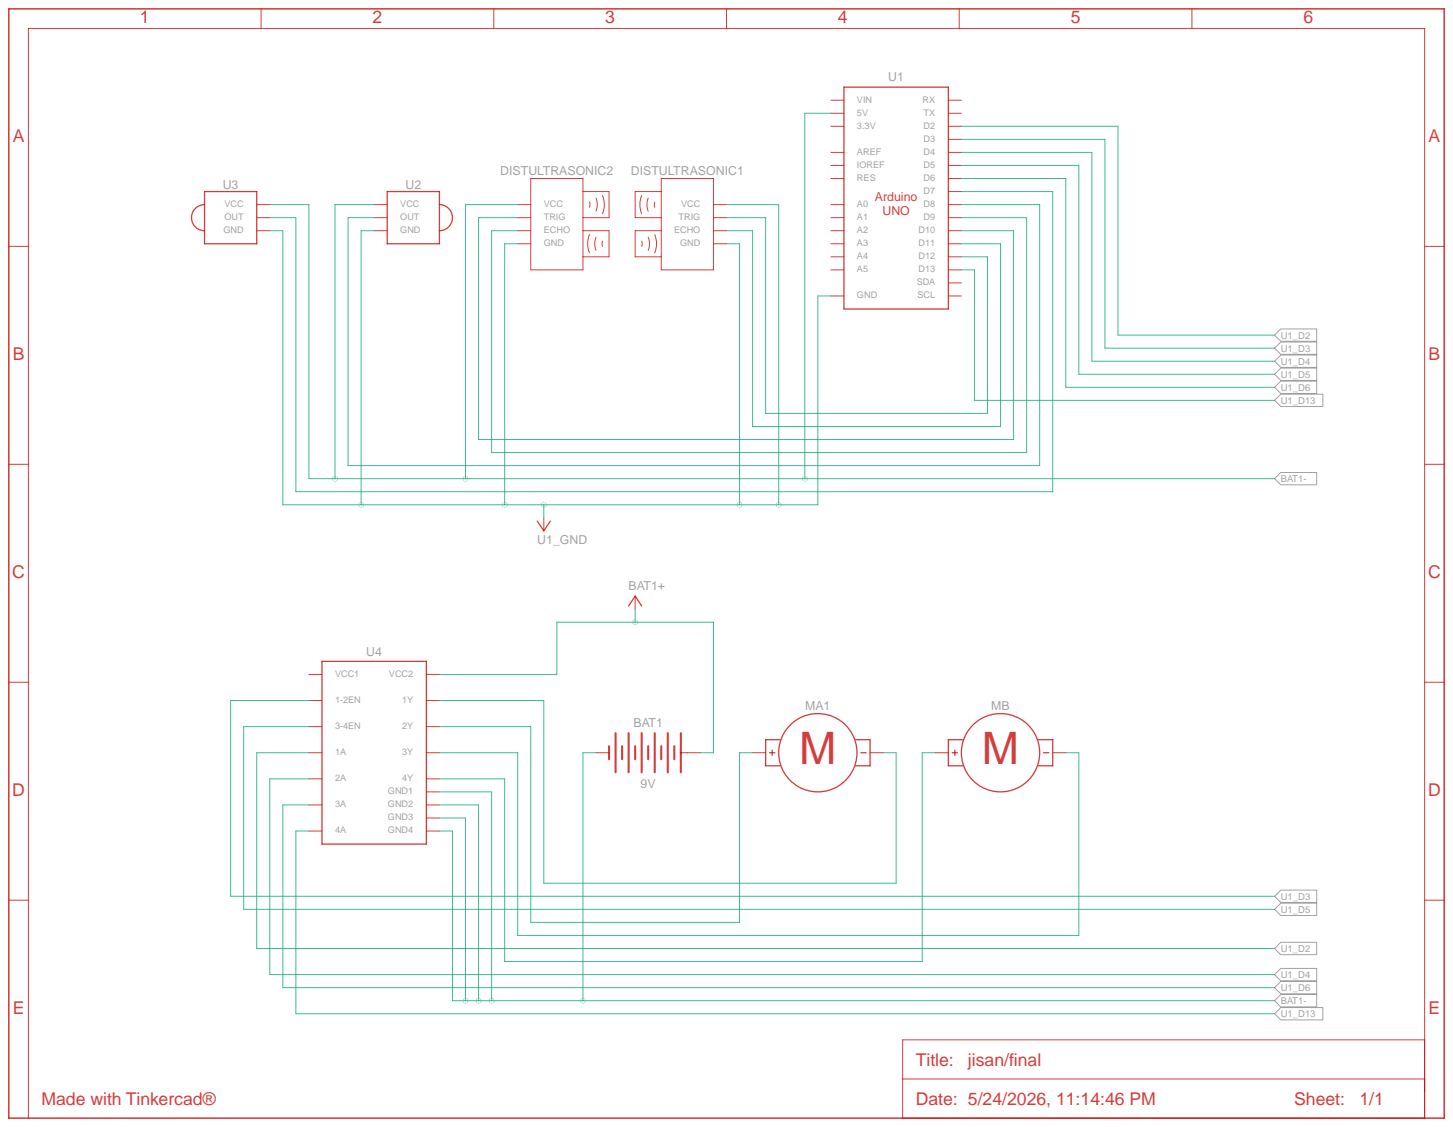
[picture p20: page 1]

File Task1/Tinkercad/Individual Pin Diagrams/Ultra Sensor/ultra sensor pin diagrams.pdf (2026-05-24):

A

1 | 2 | 3 | 4 | 5 | 6

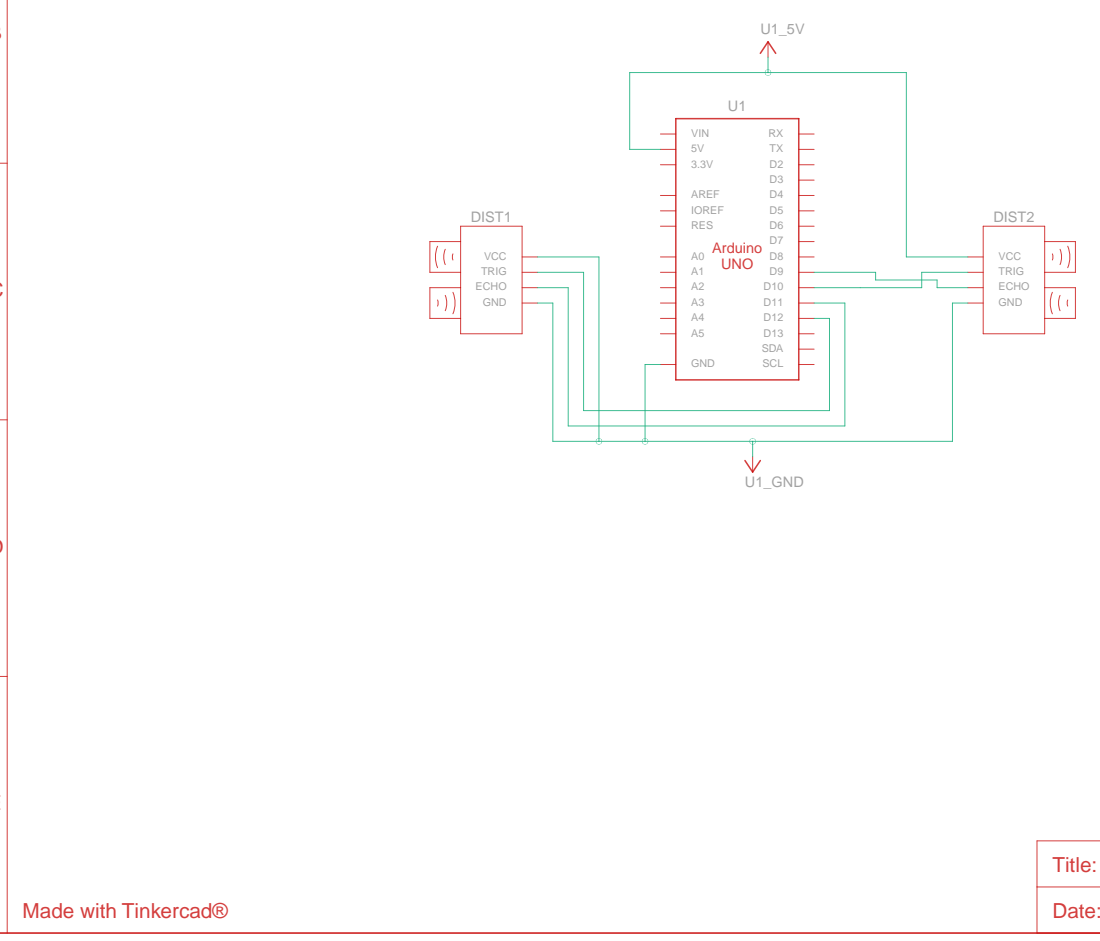
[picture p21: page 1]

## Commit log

2026-05-16 Add IR sensor file to Task1/Aynul
2026-05-16 Rename Draft to Ultra Sonic Sensor
2026-05-16 Rename Draft 3 to Motor Holder
2026-05-16 Create Battery and Breadboard
2026-05-24 Rename PHOTO-2026-05-24-19-43-51.jpg to Mashrufur/Final Assemble.jpg
2026-05-24 Rename Mashrufur/Final Assemble.jpg to Task1/Mashrufur/Final Assemble.jpg
2026-05-24 Rename Battery and Switch Assembly-2026-05-24-184048.png to Internal Block Diagram (IBD).png
2026-05-24 Create README.md
    # Task 1 – Motor Holder Design
    ## Description
    This folder contains the motor holder design for the autonomous vehicle project.
    The motor holder is used to connect and fix the DC motors to the vehicle chassis. It was designed as part of Task 1 and will be used for the first physical prototype.
    ## Uploaded Files
    - Motor holder CAD file
    - Motor holder CAD screenshot
    - Physical picture showing the motor holder connection
    ## Design Purpose
    The purpose of the motor holder is to:
    - hold the DC motor in a stable position,
    - connect the motor mechanically to the chassis,
    - support the wheel alignment,
    - allow assembly without glue, tape, or zip ties.
    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
2026-05-24 Rename Untitled Diagram.drawio.png to use case diagram.png
2026-05-24 Add files via upload
    Tinkercad simulation uses L293D motor driver.
    Real prototype uses L298N motor driver.
    Tinkercad link: https://www.tinkercad.com/things/bMiTZFzSPwb/editel?sharecode=3Lw-Ck1rJIPJ7GTSx9oekX-iGgenD7a19_9YDod6rfY
2026-05-24 Rename PHOTO-2026-05-24-22-16-20.jpg to Task1/Mashrufur/Battery & Breadboard Holder.jpg
2026-05-24 Rename Final Assemble.jpg to 1. Final Assemble.jpg
2026-05-24 Rename 1. Final Assemble.jpg to a. Final Assemble.jpg
2026-05-24 Rename a. Final Assemble.jpg to Final Assemble.jpg
2026-05-24 Rename image.png to Task1/Draft Code FlowChart.png
2026-05-24 Rename Screenshot 2026-05-24 235537.png to Task1/Aynul/IR Sensor.png
2026-05-24 Rename IR Sensor.png to IR Sensor holder.png
2026-05-24 Rename IR Sensors AYNUL.pdf to Task1/Aynul/IR Sensors Pin Diagram.pdf
2026-05-24 Rename ultra sensor pin diagrams.pdf to Task1/Jisan/ultra sensor pin diagrams.pdf
2026-05-31 Update README by removing battery connection warnings
    Removed cautionary notes about battery and connections.
